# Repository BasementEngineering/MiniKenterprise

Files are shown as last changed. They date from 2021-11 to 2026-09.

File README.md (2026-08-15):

# MOSTY DONE BUT STILL IN PROGRESS

# MiniKenterprise

## What is the Mini Kenterprise ?
The Mini Kenterprise started as a fun little weekend project and turned into a great little drone boat. Its purpose is to get people interested in tech science and ocean exploration. As such it is great for electronics enthusiasts like me but also for students in a workshop setting. 
The Mini Kenterprise, as its name might suggest, is a shrunk down version of a bigger boat. Its "big" sister is a self driving water surveying vessel that was built a couple of years ago and is documented on [Instructables](https://www.instructables.com/Building-a-Self-Driving-Boat-ArduPilot-Rover/).
While the Mini Kenterprise looks similar to it's big sister, it is way easier and also a lot chaeper to build. And it uses off-the-shelf components and fairly common tools.
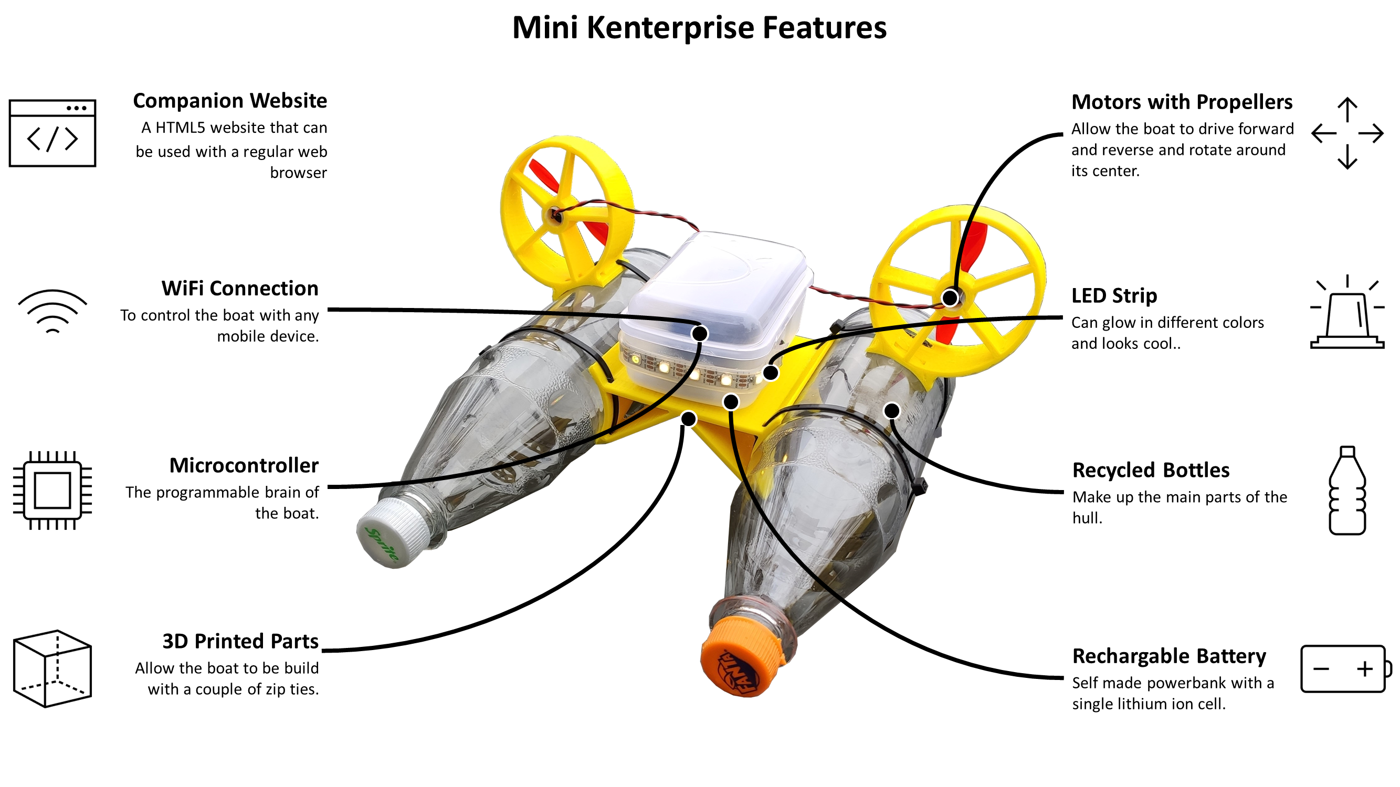
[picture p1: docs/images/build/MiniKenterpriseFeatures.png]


## Why would you want to build one ?
Building a Mini Kenterprise touches on many different engineering disciplines, including 3D printing, soldering, programming and even wireless communication and web technologies.
All packaged in a little RC boat that uses two regular plastic bottles to stay afloat and can be controlled with a smartphone. 
What makes it stand out amongst other RC boats, is that you can build it yourself.
It offers a bunch of features, that can be seen in the graphic above.
It is an air boat, meaning that it moves by using two propellers. It also has a couple of LEDs that can do a cool knight rider effect.
[Here](https://user-images.githubusercontent.com/35432032/155309053-8130b957-cc9e-41b4-a569-48ad077a3d52.mp4) is a video of the first maiden voyage of my first working prototype.

## Check out the new project website
Now most of the information on how to build your own mini kenterprise, including a dynamic bill of materials and a site to program and update it without the need for the Arduino IDE can be found [here](https://basementengineering.github.io/MiniKenterprise/).
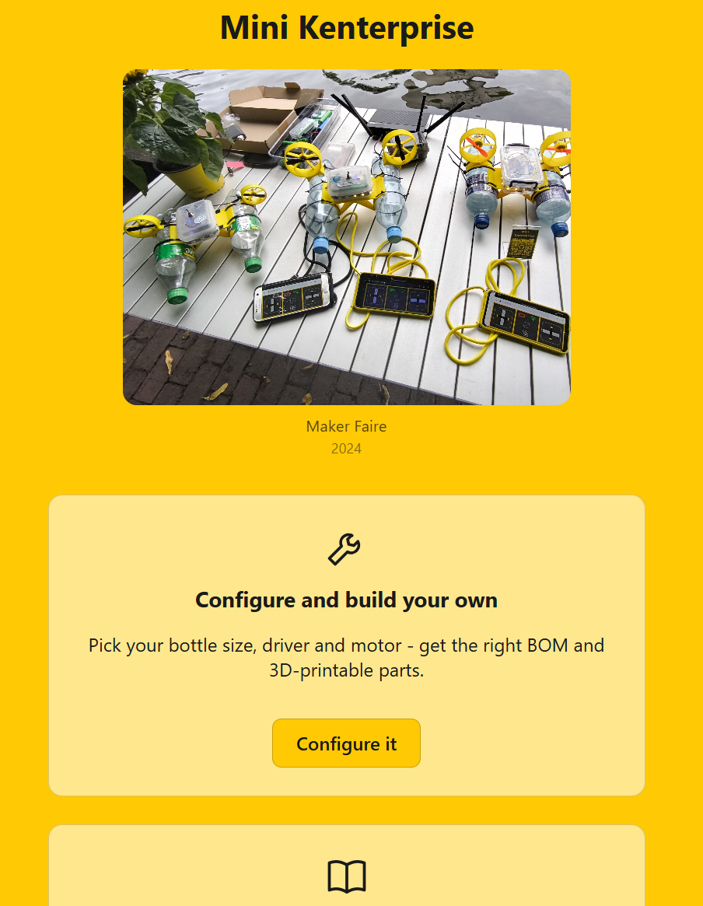
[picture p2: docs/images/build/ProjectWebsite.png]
mini kenterprise project website (https://basementengineering.github.io/MiniKenterprise/)


## Updates
- 2026|07 Programming a Mini Kenterprise no longer requires the Arduino IDE - flash it straight from your browser at the [flashing website](https://basementengineering.github.io/MiniKenterprise/). WiFi credentials and pin assignments are now changed from the boat's own settings page instead of by editing code.
- 2024|09 Working on a new unified hardware architecture for student workshops according to my best practices so far.
- 2024|08 Working on a complete rewrite of the web frontend and a new installation method, that you can already get a taste of in my [duck project](https://www.instructables.com/How-to-Build-an-RC-Duck-With-Arduino-and-Wi-Fi/) with it's nice [duck flashing website](https://basementengineering.github.io/Duck/)

## How Do I Build One ?
Keep in mind that the Mini Kenterprise is not set in stone - it's not an off-the-shelf kit with instructions that tell you 100% exactly how to build it. That said, especially for electronics beginners and student workshops, it's great to have a guide to follow.

The full step-by-step build guide - materials, bottle prep, 3D printing, electronics assembly, soldering, testing, and first launch, all with photos - is on the [project site's Build Guide page](https://basementengineering.github.io/MiniKenterprise/build/) (source: [`docs/build/BuildGuide.md`](docs/build/BuildGuide.md)).

For everything else - the bill of materials, 3D-printable files for your chosen bottle/motor/prop combo, and flashing the firmware straight from your browser - head to the [project site](https://basementengineering.github.io/MiniKenterprise/).

## How does it work? 
The Mini Kenterprise is a "smart" device that can "talk internet". It works as seen in the graphic below. It can host its own WiFi network (access point mode) or connect to an existing WiFi network (station mode). Through this WiFi network it can talk to a variety of other devices, such as the smartphone, that you might have in your pocket, or the laptop, that you might read this on.
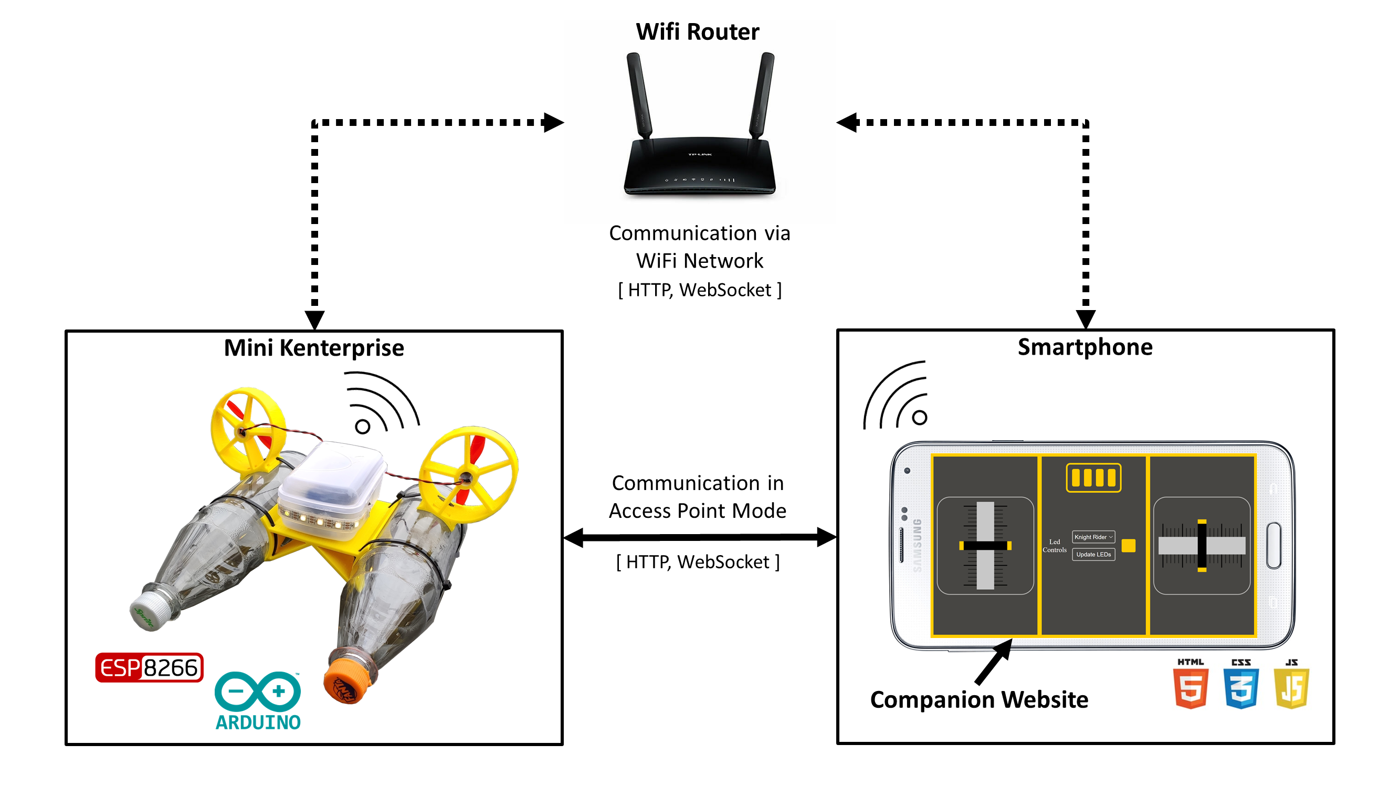
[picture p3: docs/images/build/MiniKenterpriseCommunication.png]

Next to the WiFi connection the boat also has a little webserver, that can serve a companion website. This companion website is a little bit of code, that your phone can access and run, by talking to the server via HTTP. That might sound complicated, but it is simply a matter of opening a websbrowser and entering the boats IP address into the address field.
Once this website is on your phone, it opens a two-way-tunnel to the boats controller. This is called a websocket and it allows the website to send motor control commands to the boat and the boat to send back sensor data.
Thats basically it. The website also has a bunch of nice little buttons and text fields so the data doesn't look that bad. And it features two joysticks that allow you to take control of the boat using your touchscreeen.

## Project History
Before you can start a new DIY Project from Scratch, you will have to do a lot of planning. A lot of designing, building, testing and improving.
Luckyly for you, i already did that and went through a couple of prototypes.
So you will only have to read this if you are interested in the process.
I started with a 3D model, that I designed in Fusion 360. Below you can see a rendering of the latest version.
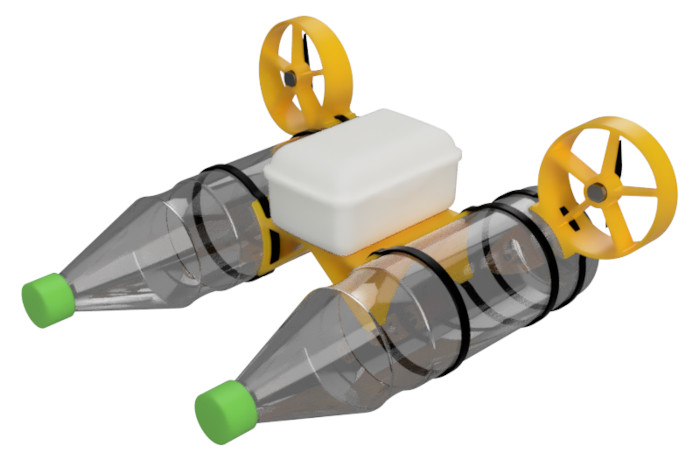
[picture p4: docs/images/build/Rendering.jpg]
Rendering

The circuit diagram was done in PowerPoint. A more professional way would be to draw the circuit diagram in an E-CAD tool such as KiCAD.
However I prefer powerpoint, as it is much easier to understand for Non-Electronics-Experts.

## Hardware Versions So Far
Every variant shares the same type of brain and the same code and user interface. What differs is the size, the motors and the energy source.

This little guide focusses on my "Version 1". This version was built especially for a student workshop, with parts that can be purchased from german suppliers.

Here is a little overview of the other versions in the repository:

- Version 0 aka failure: Was a first test, did not really work out that well.
- Version 1 aka workshop version: Beginner friendly version that was developed with components from german suppliers.
- Version 2 aka small version: Smaller Version that uses 0.5l bottles and small props.
- Version 3 aka fast version: Medium sized version with big fans and 0.75l bottles. Optimized for low weight ans high power.

This guide focusses on version 1 but I have also built other versions that can also be found in this repository.

Here are the major technical differences in a table.
| Version Name 	| Motor | Motor Diameter | Fan Diameter | Bottle Size |
|---|---|---|---|---|
| Version 1	| Arduino 5V Motor Module 	| 12 mm | 75 mm | 1 L	|
| Version 2	| 3.7V Drone Motors 		| 7 mm 	| 45 mm | 0.5 L	|
| Version 2	| 3.7V Motors 			 | 12 mm | 75 mm | 0.75 L|

This repository contains images, circuit diagrams and material list for each version. These files and a dedicated little README can be found under [`docs/images/build/VersionX`](docs/images/build/).

## Key Takeaways So Far
Motors consume a ton of power when starting up and microcontrollers don't like their voltage to dip. In my testing with bigger DC motors, they often didn't even manage to start or starting them took out the entire boat and reset the microcontroller. The reason is the insanely high current draw.
A solution is to either go with a battery that has a high C-rating (discharge rate) and an accompanying battery management system (BMS) that can handle the current. Or to use a low current motor.
In my experiments coreless dc motors proved to consume significantly less power and managed to start up with a small BMS-Board and didn't take the battery out. These motors can be found in cheap tiny drones at the toy store and they are way more fun, than regular dc motors. However, they don't like to be speed regulated, at least my Mini Kenterprise is having trouble going straight with it. Gluing a fin onto the hull, will probably be the easiest fix for that.

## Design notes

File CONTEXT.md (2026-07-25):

# Mini Kenterprise

An ESP8266-based RC boat that people build themselves from a workshop kit, then control from a browser. This context covers the firmware (`MiniKenterpriseCode/`) and its companion web tooling (`minikenterprise_frontend/`, the public site in `docs/`) that get someone from a freshly-soldered board to a boat they can drive, without an Arduino IDE install.

## Language

**Settings**:
The single flat, runtime-editable record of everything a builder might need to change without recompiling: WiFi mode/credentials and the named GPIO pin assignments. Persisted in EEPROM behind a magic-byte validity check; falls back to the compiled-in defaults on first boot or corruption.
_Avoid_: Config (that's the compile-time defaults in `Config.h`, not the runtime record), Preferences (not used here — that's Duck's NVS-based approach).

**Config.h defaults**:
The compiled-in fallback values (pins, AP SSID/password, PWM limits) used only to seed `Settings` the first time the device boots, or after a factory reset. Never read directly at runtime once `Settings` has loaded.
_Avoid_: "the config" as a synonym for `Settings` — they're different lifecycles (one is baked into the firmware image, the other lives in EEPROM and survives reflashing).

**AP mode / Station mode**:
The two WiFi roles the boat can run in, chosen at runtime via `Settings.apMode` (not compile-time anymore). AP mode: the boat hosts its own network and a controller connects to it directly. Station mode: the boat joins an existing WiFi network. If Station mode fails to connect within its timeout, the boat automatically falls back to AP mode so it's never left unreachable.
_Avoid_: "hotspot" for AP mode.

**the site**:
The general public web presence for the project, published from `docs/` (formerly its own `flash-site/` folder — moved so it sits as a sibling of `docs/images/` and `docs/materials/` and can link to them directly, no copying; see `docs/adr/0007-consolidate-site-and-docs-under-docs-folder.md`). Its home page (`index.html`) offers three paths: flashing a prebuilt firmware `.bin` over Web Serial via esp-web-tools (`flash.html`, the "visit a page, click a button" install experience), configuring a new build (`configure.html`, the Variant picker + BOM + STL downloads — see Configurator), and the Build Guide (`docs/build/index.html`, which fetches and renders `docs/build/BuildGuide.md` client-side via the `marked` library loaded from a CDN — no build step, same pattern as esp-web-tools). `docs/materials/BOM.md` remains a maintained, human-readable BOM reference alongside the interactive Configurator, not archival — the material that's actually archival (old workshop slide decks/handouts) lives outside git entirely, in the gitignored top-level `workshop-archive/`.
_Avoid_: "the website" (ambiguous with the on-device control UI served by the firmware itself). "flash-site" (the old folder name — gone; don't reintroduce it in new docs, though you'll still see it in history and older ADRs). "The flashing site" alone, now that it's not flashing-only.

**Variant**:
One specific, buildable combination of the four choices a builder makes — bottle size, motor driver, motor, and its (motor-dependent) prop diameter — that the Configurator resolves to a concrete BOM and a concrete set of STL files to print. Not every combination of the four choices is a Variant; only ones with real, mapped print files in the Configurator's data are offered.
_Avoid_: "Version" (the numbered pin-layout naming this project already retired in `Config.h`'s `// previously "VERSION3"` comment; not being reintroduced for hardware configurations either — note the existing `README.md` "Hardware Versions So Far" section predates this and isn't being renamed as part of this). "Build" (ambiguous with a compiled firmware binary or an `npm run build`).

**Configurator**:
`docs/configure.html` and its `docs/js/` modules — lets a prospective builder pick a Variant and see the resulting BOM and STL download links, before anything is built or flashed. Distinct from the Control UI (runs on an already-built, already-flashed boat) and from flashing (installs firmware onto already-built hardware).

**Control UI**:
The on-device web app (built from `minikenterprise_frontend/`, embedded into the firmware binary as PROGMEM byte arrays) that a builder's browser loads directly from the boat over WiFi, to drive it and adjust `Settings`.
_Avoid_: "frontend" alone — ambiguous between this and the site.

**Dev stub**:
A dev-only Node script (`minikenterprise_frontend/dev-stub.js`) that mocks both wire protocols the Control UI speaks to the real firmware — the `/api/settings` GET/POST HTTP protocol and the boat-control WebSocket on `:81` — so the whole Control UI, settings page and live boat control alike, can be developed, driven, and debugged locally without a flashed board. It logs every decoded control command to the terminal and replies to heartbeats/pushes simulated status so the UI behaves as if connected.
_Avoid_: confusing with `FrontendServer` or the firmware's `WebSocketsServer` (the real on-device servers) — the stub only exists on a developer's machine, never in firmware, and mirrors protocol shape only, not EEPROM storage, restart semantics, or real motor/LED behavior.

## Example dialogue

> "Where does someone change the boat's WiFi password?"
> "The Control UI's settings page — it reads and writes `Settings`, not `Config.h`. `Config.h` only matters on first boot, to seed the default `Settings`."
>
> "And if they type the wrong WiFi password for Station mode?"
> "It tries to connect, times out, and falls back to AP mode automatically — they reconnect to the boat's own network and fix it from there."
>
> "Is that the same page as the site?"
> "No — the site (`docs/`) is a separate, public site. Its flashing page installs the `.bin` the first time. The Control UI only exists once the firmware is already on the board."
>
> "Where do I find out what parts I need to build one?"
> "The site's Configurator — pick a Variant (bottle size, driver, motor, prop) and it resolves the BOM and STL downloads for that exact combination. `docs/materials/BOM.md` is still a maintained reference too, just not interactive."

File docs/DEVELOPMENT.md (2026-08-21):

# Development Quickstart

This repo has three independently runnable pieces: the Control UI **frontend** (`minikenterprise_frontend/`), the **firmware** (`MiniKenterpriseCode/`), and the public **site** (`docs/`). Each section below covers one.

## Frontend

```
cd minikenterprise_frontend
npm install        # once
npm run dev-stub   # terminal A - mocks the boat's settings HTTP API (:8787) and control WebSocket (:81)
npm run dev        # terminal B - Vite dev server
```

Open:
- Control UI: http://localhost:5173/
- Settings page: http://localhost:5173/settings/

No hardware needed — `dev-stub` fakes both wire protocols the firmware speaks (settings + boat control), replies to heartbeats, and drifts simulated battery/network status. Watch the `dev-stub` terminal to see every command the frontend sends, decoded live (e.g. `[control] recv: ControlLR 45 -10`). See `docs/adr/0005-unify-dev-stub-for-boat-control-and-settings.md`.

## Building the frontend and embedding it into the firmware

The firmware serves the frontend from flash as PROGMEM byte arrays, not from a filesystem (`docs/adr/0001-embed-frontend-as-progmem.md`), so it has to be re-encoded after every frontend change.

Full pipeline, one command from the repo root (builds, encodes, and copies the generated headers into `MiniKenterpriseCode/`):
```
.\deployFrontend.ps1
```

Or step by step:
```
cd minikenterprise_frontend
npm run build                              # -> dist/
python ../tools/encodeInArduino.py dist     # -> dist/website_content.h + website_functions.h
```

**Size**: `encodeInArduino.py` prints a per-file size and a total, e.g.:
```
Total embedded size: 76829 bytes across 8 files
```
That's flash usage (PROGMEM), not RAM — it doesn't compete with the ESP8266's heap. The number that actually matters is the "Sketch uses X bytes (Y%) of program storage space" line the Arduino IDE/`arduino-cli` prints after compiling `MiniKenterpriseCode.ino`, which is bounded by the flash-size partition chosen for the board (Tools > Flash Size in the IDE). Check that after any frontend growth, not just the embed-step total — there's no automated budget check for either number yet.

## Testing options

No automated test suite exists yet — the project relies on manual testing instead:
- **Frontend only**: `npm run dev-stub` + `npm run dev` (above), drive the Control UI/settings page in a browser, and watch the stub terminal for exactly what gets sent. This isolates frontend bugs from backend/hardware bugs before ever touching a board.
- **Full firmware, on real hardware**: flash a board (below) and exercise the actual control loop, motor output, EEPROM-backed settings persistence, and AP/Station WiFi fallback — none of which the stub simulates.

## Firmware: developing and uploading

Source lives in `MiniKenterpriseCode/`, with `MiniKenterpriseCode.ino` as the sketch entry point.

- **Arduino IDE** (1.x or 2.x): open `MiniKenterpriseCode.ino`, select your board (Wemos D1 Mini: "LOLIN(WEMOS) D1 R2 & mini"), then Sketch > Upload.
- **arduino-cli**:
  ```
  arduino-cli compile --fqbn esp8266:esp8266:d1_mini MiniKenterpriseCode
  arduino-cli upload --fqbn esp8266:esp8266:d1_mini -p <PORT> MiniKenterpriseCode
  ```

Re-run the frontend build/embed step above first if you changed anything under `minikenterprise_frontend/` — the checked-in `website_content.h`/`website_functions.h` don't regenerate themselves.

## The site (`docs/`): running it locally and releasing

`docs/` is a plain static site (no build step) published via GitHub Pages (`.github/workflows/pages.yml` uploads `docs/` as-is — no CI build step either). It lives under `docs/` specifically so it can reference `docs/images/` and `docs/materials/` with plain relative links, instead of copying them into a separate folder. It has three paths from its home page: flashing a prebuilt `.bin` straight from the browser via Web Serial (`flash.html`), configuring a new build — picking a bottle/driver/motor/prop Variant to get the right BOM and STL downloads (`configure.html`) — and the Build Guide (`docs/build/index.html`), which fetches `docs/build/BuildGuide.md` and renders it client-side with the `marked` library loaded from a CDN (same no-build-step approach as `flash.html`'s esp-web-tools). Since `docs/build/index.html` sits in the same folder as `BuildGuide.md`, the guide's relative image/file links (e.g. `../images/build/...`, `../../3dFiles`) resolve correctly without any rewriting — edit `BuildGuide.md` like any other markdown file and the rendered page picks it up as-is.

`BuildGuide.md` always covers the current recommended Variant only (Vorarlberg as of this writing) — older guides for superseded setups aren't deleted, just renamed to `BuildGuide_<Name>.md` and added to the `GUIDES` map in `docs/build/index.html`'s script, which switches between them via a `?guide=<name>` query param (the same query-string-as-state idiom `configure.html`'s `js/urlState.js` uses for Variant picks). Add a small link for each archived guide to the `.guide-switcher` nav in `docs/build/index.html` so it stays reachable.

To preview any of them locally:
```
cd docs
python -m http.server 8080
```
Open http://localhost:8080 — Web Serial requires a secure context, and `localhost` counts as one, so this works without HTTPS. Actually flashing still needs a real board plugged in over USB, in Chrome or Edge. `configure.html` needs no hardware; its STL download links point at `raw.githubusercontent.com/BasementEngineering/MiniKenterprise/main/3dFiles/...`, so they fetch from the pushed `main` branch even when previewing locally — a new STL you haven't pushed yet won't download until it's on `main`. The Build Guide needs internet access (to load `marked` from the CDN) even when previewing locally.

The home-page gallery registers `docs/sw.js` as a service worker. After one successful online visit, it caches the home page shell, gallery manifest, and every current gallery image so the carousel can run offline. Cache paths are derived from the service worker scope, so this works on the GitHub Pages project URL and at the local preview URL.

### Releasing a new firmware build

1. Build the frontend and regenerate the embedded-website headers: `.\deployFrontend.ps1` (repo root).
2. Compile `MiniKenterpriseCode.ino` (Arduino IDE or `arduino-cli`) and export the binary as `esp8266.bin`.
3. Copy it to `docs/firmware/esp8266.bin`, overwriting the previous one.
4. Bump `"version"` in `docs/firmware/manifest.json`.
5. Commit and push — the Pages workflow republishes `docs/` automatically.

### Releasing a configurator/BOM update

1. Update `docs/materials/motorsAndProps.csv` and/or hand-edit `docs/js/data/variants.js` to reflect new motors/props/BOM parts/STL mappings. If you add a new fan-enclosure STL, drop it into the right `3dFiles/<bottle>_Bottle/` folder — name it `FanEnclosure_<bottle>_M<motorDiameter>_P<propDiameter>.stl` to be picked up automatically, or add an entry to `variants.js`'s `legacyOverrides` if it doesn't follow that convention. Component/gallery photos live under `docs/images/components/` and `docs/images/gallery/` respectively and are referenced directly — no copy step.
2. Run `.\deployConfiguratorAssets.ps1` (repo root) — this rescans `3dFiles/` and regenerates `docs/js/data/stl-manifest.json`.
3. Preview locally (above) — click through `configure.html`, checking that picker enabling/disabling looks right. STL download links will only resolve against files already on `main`.
4. Commit `docs/js/data/variants.js` and `stl-manifest.json` (and any new files under `3dFiles/`), and push — the Pages workflow republishes `docs/` automatically.

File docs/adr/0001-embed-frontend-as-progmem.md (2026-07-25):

# Embed the Control UI as PROGMEM byte arrays instead of a filesystem

The Control UI used to be served from SPIFFS, which required a separate "ESP8266 Sketch Data Upload" step only supported by Arduino IDE 1.x — the main friction point in getting a Mini Kenterprise running. We're instead building the frontend with Vite and baking the output directly into the firmware as `PROGMEM` byte arrays (ported from the Duck project's `encodeInArduino.py`), so flashing the firmware is the only step. The trade-off is a larger firmware binary and an extra build step before compiling, but it removes the filesystem entirely and works with any Arduino toolchain (including IDE 2.x and `arduino-cli`).

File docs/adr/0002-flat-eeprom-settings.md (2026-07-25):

# Flat EEPROM struct for runtime settings, not Preferences/LittleFS/JSON

Duck (a sibling project sharing this firmware base) built a `Preferences`-backed, JSON-schema-driven settings system supporting pluggable per-motor driver types — flexible, but the kind of "support every hardware variant" complexity that previously made this codebase hard to maintain. Mini Kenterprise's settings are deliberately scoped down to what builders actually asked for: WiFi credentials and named pin numbers, nothing pluggable. We're storing this as one fixed-size struct via the ESP8266 core's EEPROM-emulation library, validated with a magic byte, with no JSON library or filesystem involved. If a genuine need for per-hardware-variant driver configuration reappears, that's a separate future decision, not something to bolt onto this struct.

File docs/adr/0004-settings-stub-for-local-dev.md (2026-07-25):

# Local Settings stub for offline dev/testing

The Settings page's `/api/settings` GET/POST calls have no backend when running `npm run dev`, blocking local iteration on layout and save/load behavior before flashing hardware. We considered proxying to a real device on the LAN (requires hardware always on hand) and a client-side fetch mock inside `settings.js` (duplicates protocol parsing into production code). Instead we added a small standalone dev-only Node script (`minikenterprise_frontend/settings-stub.js`) that fakes the same `key=value` wire protocol from an in-memory object, proxied via Vite. It mirrors the protocol shape only, not EEPROM storage or restart semantics, so it's a test double alongside the real `Settings` (ADR 0002), not a second implementation of it.

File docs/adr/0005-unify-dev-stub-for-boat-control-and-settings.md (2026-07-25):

# Extend the Settings stub into a unified dev stub covering boat control too

`docs/adr/0004-settings-stub-for-local-dev.md` gave the Settings page a local backend, but the Control UI's boat-control channel (a WebSocket on `:81`, see `MiniKenterpriseCode/Parser.h`) had no equivalent — with nothing listening on `:81` during `npm run dev`, the socket fails silently and the UI just sits in its offline/error state, indistinguishable from a real firmware bug. That ambiguity made it hard to separate frontend bugs from backend/hardware bugs while developing without a flashed board.

We replaced `settings-stub.js` with `minikenterprise_frontend/dev-stub.js`, a single dev-only Node process that mocks both wire protocols the Control UI speaks: the existing `/api/settings` HTTP mock, unchanged, plus a new WebSocket mock on `:81` (using the `ws` package) that decodes and logs every incoming control command to the terminal, replies to `Heartbeat` so the UI's online/offline state behaves correctly, and pushes slowly drifting `Status` messages so battery/network indicators visibly react. The control mock reuses `Parser`/`Communication_Commands` from `src/my_modules/parser.js` directly rather than reimplementing the wire format, so the mock can't drift out of sync with the real frontend protocol logic.

This gives one command (`npm run dev-stub`) and one terminal to fully develop and debug the Control UI — both pages, both channels — without hardware, and to watch exactly what the frontend sends before deciding whether a bug is a frontend, backend/firmware, or hardware issue. As before, it mirrors protocol shape only (no EEPROM persistence, no real motor/LED behavior, no restart semantics) — a test double, not a second implementation.

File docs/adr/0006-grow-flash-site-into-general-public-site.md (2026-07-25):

# Grow flash-site into the general public site, not a separate configurator project

Builders now need to pick a bottle size, driver, motor and prop before they can get a correct BOM and STL set — a real feature (the Configurator), not a documentation tweak. We're adding it as `configure.html` inside the existing `flash-site/` directory, alongside a new `flash.html` and a chooser `index.html`, rather than starting a second static site or repo. `flash-site/` was already a GitHub Pages target with its own publish workflow, its own "no build step" convention, and its own stylesheet — reusing all three means one Pages workflow, one link from the root `README.md`, and one place a builder lands regardless of which of the two things (flash vs. configure) they came for. The cost is that `flash-site` becomes a mild misnomer — it's no longer just the flashing page — and its `flash-site/**`-triggered deploy now couples releases of two previously-unrelated concerns (firmware distribution and parts/print selection). We're accepting that cost rather than renaming the folder or splitting the deploy pipeline; the folder keeps its name.

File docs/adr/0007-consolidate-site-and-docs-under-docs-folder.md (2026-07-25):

# Move the public site into docs/, stop copying assets into it, drop the workshop archive from git

`flash-site/` needed everything GitHub Pages would serve to physically live inside it, since Pages publishes one directory as-is with no build step. That meant `deployConfiguratorAssets.ps1` copied BOM component photos, variant hero photos, and a subset of `3dFiles/` STLs into `flash-site/img/` and `flash-site/downloads/`, and every copy got committed to git alongside its source — doubling real binary content for no benefit. We're moving the site itself into `docs/` (its HTML/CSS/JS/firmware, previously `flash-site/*`) so it becomes a sibling of `docs/images/` and `docs/materials/` instead of a separate folder needing copies of them: the Configurator now links to `docs/images/components/...` and `docs/images/gallery/...` directly, and STL "download" links point straight at `raw.githubusercontent.com/BasementEngineering/MiniKenterprise/main/3dFiles/...` (an accepted pattern for occasional, user-initiated downloads, as opposed to images loaded on every page view, which stay served by Pages' own CDN). `deployConfiguratorAssets.ps1` now only rescans `3dFiles/` and regenerates the tiny `stl-manifest.json`; the Pages workflow (`path: docs`) needs no build step of its own. The site's public URL is unchanged, since `docs/index.html` still serves at the Pages root.

Existing images were reorganized into `docs/images/{components,gallery,build}/` — `components/` for BOM part photos (was `docs/materials/images/`), `gallery/` for "finished boat" inspiration photos (was root `images/*_Variant_*`, meant to grow substantially once a scrolling gallery ships on the site), and `build/` for everything else that used to live in the repo-root `images/` folder (hardware-version galleries, soldering tips, diagrams), moved wholesale. The repo-root `README.md`'s old step-by-step build walkthrough moved into `docs/build/BuildGuide.md` alongside those photos, leaving `README.md` a short entry point that links out to the guide and the site for BOM/3D files/flashing — the intent being that `docs/` grows into a one-stop shop (BOM with purchasing links, build steps, pinout for the recommended version, flashing) while the root README stays a lean front door.

Also folded in here: the old workshop presentation archive (`docs/workshop/`, several hundred MB of pptx/docx/pdf, never actually committed) moved to a gitignored top-level `workshop-archive/` — kept on disk, never pushed to GitHub, and no longer nested under whatever `docs/` publishes.

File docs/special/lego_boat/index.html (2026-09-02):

← Back to Mini Kenterprise

Mini Kenterprise Special Edition

# LEGO Mini Kenterprise

LEGO Mini Kenterprise pairs the standard Mini Kenterprise electronics with two 3D-printed paddle wheels, driven by waterproof N20 gear motors, bolted onto a LEGO boat hull. This is a fixed reference build, made for builders who want to reproduce this particular project rather than configure a boat.

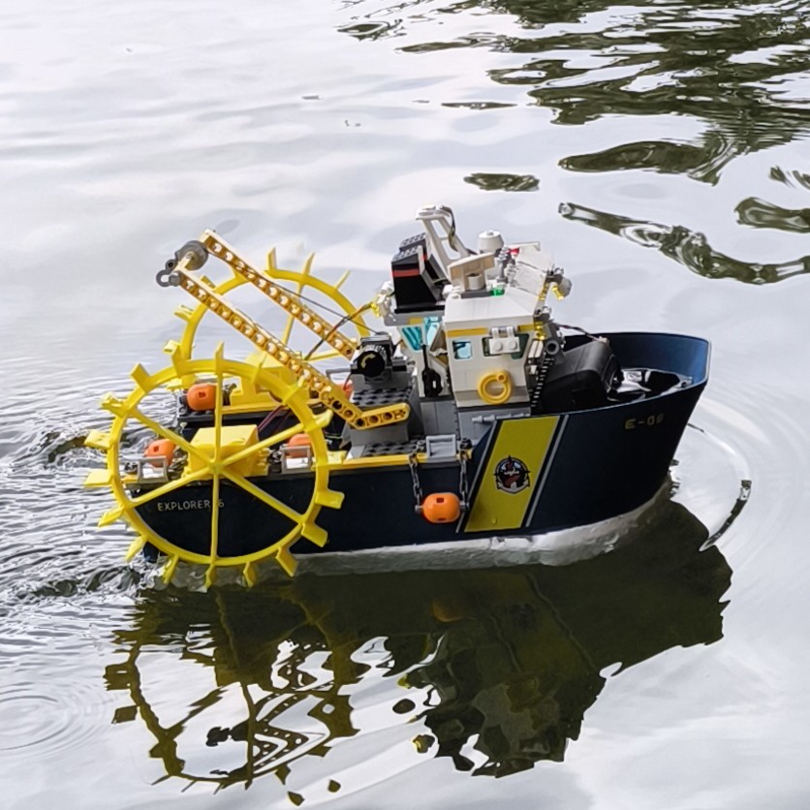
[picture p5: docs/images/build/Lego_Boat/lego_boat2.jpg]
LEGO Mini Kenterprise afloat, showing the LEGO hull and one of its paddle wheels


## Reference bill of materials

This list documents the reference build only. It intentionally has no purchasing links, as I won't be able to keep them up to date. Refer to the original Kenterprise components for sourcing. You will have to search for the special parts yourself in your online store of choice.

Part | Qty. | Reference notes
LEGO boat hull | 1 | Provides the hull and superstructure. Any similarly-sized LEGO ship set works - ours was an exploration/tug-style set.
Waterproof N20 gear motor | 2 | One motor drives each paddle wheel. Sourced as "DC 3V 6V Waterproof N20 DC Gear Motor 48RPM-96RPM Slow Speed".
5V USB power bank | 1 | Powers the whole boat directly - no separate battery, charger, or booster circuit needed.
Wemos D1 Mini | 1 | Microcontroller for the control platform, same as the standard build.
DRV8833 dual H-bridge driver | 1 | Drives the two motors.
Prototype board and pin headers | 1 | For the controller and power wiring.
Toggle switch | 1 | Main power switch.
Hookup wire, heat-shrink tubing, M3 hardware, and standoffs | As needed | Choose lengths to suit the printed motor mounts and your wiring.

## 3D-printable parts

Print two of each - one motor mount and one paddle wheel per side. Download links point directly to the project repository.

- Download MotorMount.stl (https://raw.githubusercontent.com/BasementEngineering/MiniKenterprise/main/3dFiles/special/lego_boat/MotorMount.stl)
- Download Waterwheel.stl (https://raw.githubusercontent.com/BasementEngineering/MiniKenterprise/main/3dFiles/special/lego_boat/Waterwheel.stl)

## Reference build

LEGO Mini Kenterprise afloat, three-quarter view

Completed boat, underway.

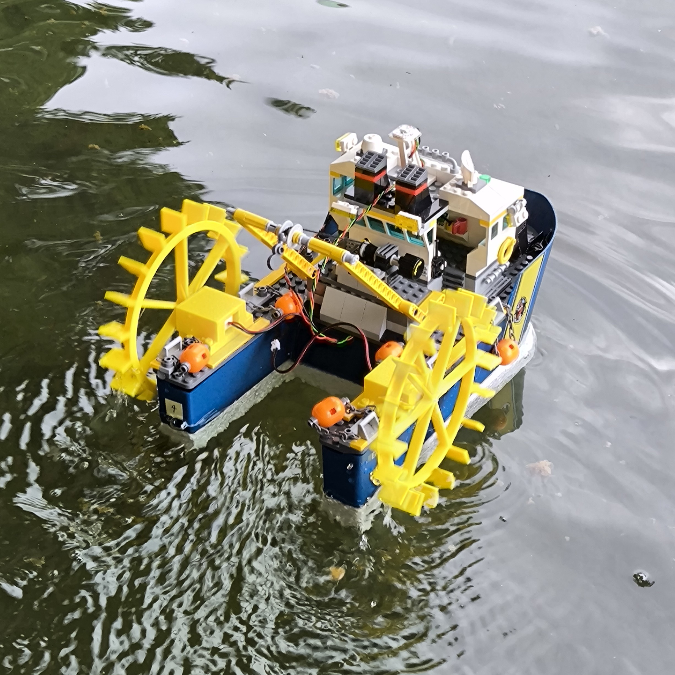
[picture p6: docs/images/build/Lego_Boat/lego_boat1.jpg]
Close-up of the two 3D-printed paddle wheels and motor mounts


Paddle wheels and motor mounts, one per side.

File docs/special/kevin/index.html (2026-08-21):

← Back to Mini Kenterprise

Mini Kenterprise Special Edition

# Kevin

Kevin is a two-wheel robotic car built around the Mini Kenterprise control platform. This is a fixed reference build, made for builders who want to reproduce this particular project rather than configure a boat.

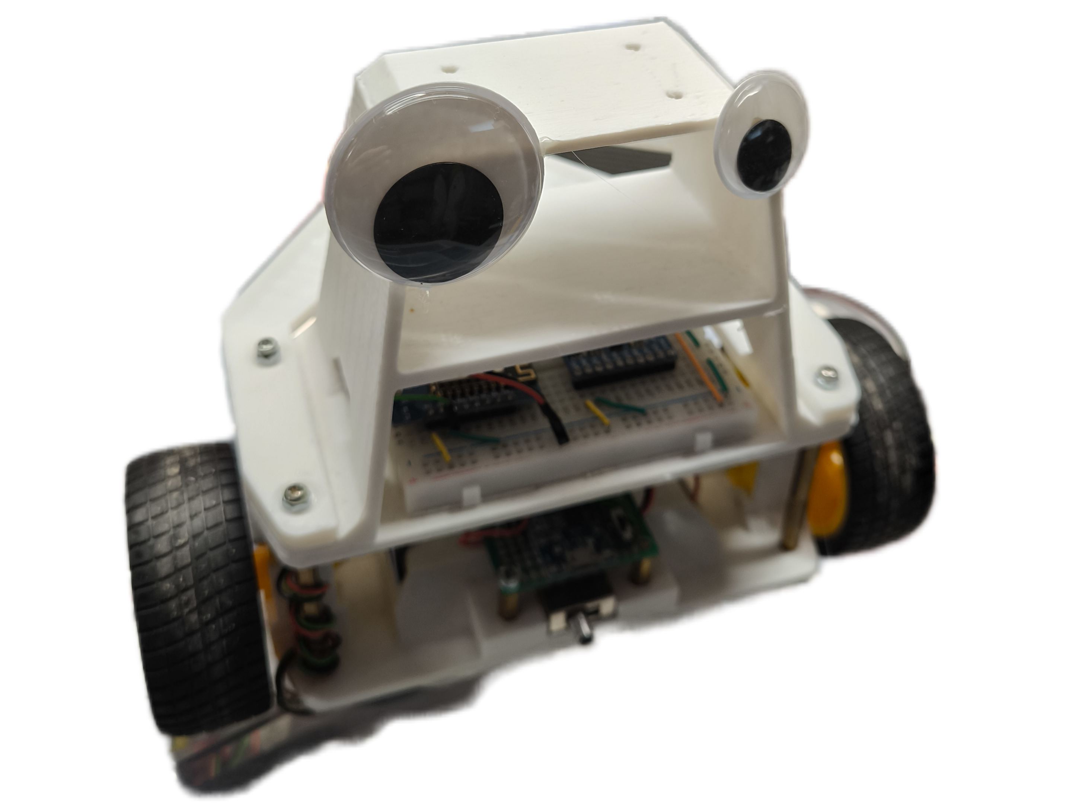
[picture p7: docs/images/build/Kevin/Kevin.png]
Kevin, the assembled two-wheel robotic car


## Reference bill of materials

This list documents the reference build only. It intentionally has no purchasing links, as I won't be able to keep them up to date. Refer to the original Kenterprise components for sourcing. You will have to search for the special parts yourself in your online store of choice.

Part | Qty. | Reference notes
TT gear motor | 2 | One motor drives each wheel.
Compatible wheel | 2 | Used with the TT gear motors.
Wemos D1 Mini | 1 | Microcontroller for the control platform.
DRV8833 dual H-bridge driver | 1 | Drives the two motors.
18650 Li-Ion cell | 1 | Power source for the reference build.
TP4056 charging module | 1 | Used for charging the 18650 cell, charger only.
1S 15A Li-Ion BMS board | 1 | Used to protect the battery.
Prototype board and pin headers | 1 | For the controller and power wiring.
Toggle switch | 1 | Main power switch.
Hookup wire, heat-shrink tubing, M3 hardware, and standoffs | As needed | Choose lengths to suit the printed chassis and your wiring.

## 3D-printable parts

The chassis is made from the four files below. Download links point directly to the project repository.

- Download Baseplate.stl (https://raw.githubusercontent.com/BasementEngineering/MiniKenterprise/main/3dFiles/special/kevin/Baseplate.stl)
- Download MiddlePlate.stl (https://raw.githubusercontent.com/BasementEngineering/MiniKenterprise/main/3dFiles/special/kevin/MiddlePlate.stl)
- Download RearWheel_Holder.stl (https://raw.githubusercontent.com/BasementEngineering/MiniKenterprise/main/3dFiles/special/kevin/RearWheel_Holder.stl)
- Download top.stl (https://raw.githubusercontent.com/BasementEngineering/MiniKenterprise/main/3dFiles/special/kevin/top.stl)

## Reference build

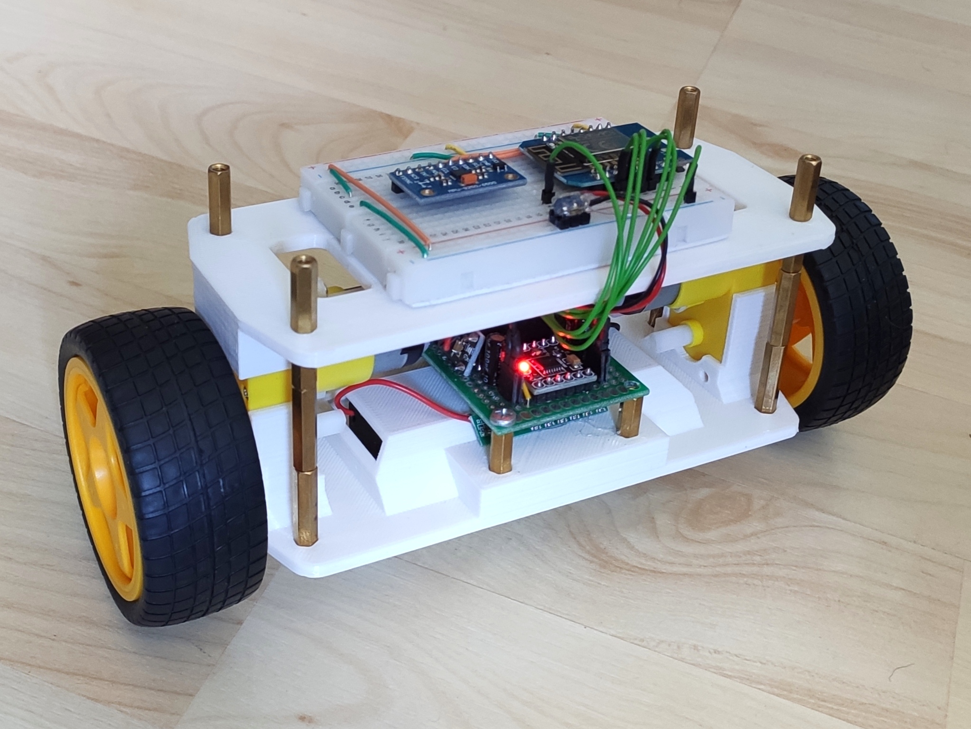
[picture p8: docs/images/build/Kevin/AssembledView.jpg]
Assembled Kevin robotic car


Completed chassis.

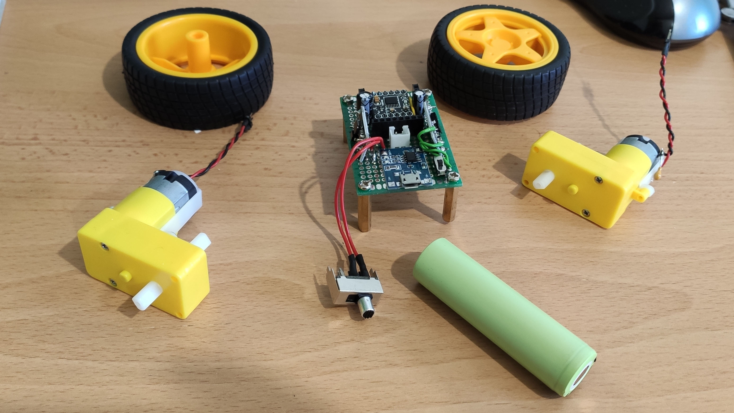
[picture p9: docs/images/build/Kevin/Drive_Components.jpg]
Kevin's wheels, gear motors, controller board, and battery


Drive, battery, and control components.

Top view of Kevin's battery compartment

Battery compartment from above.

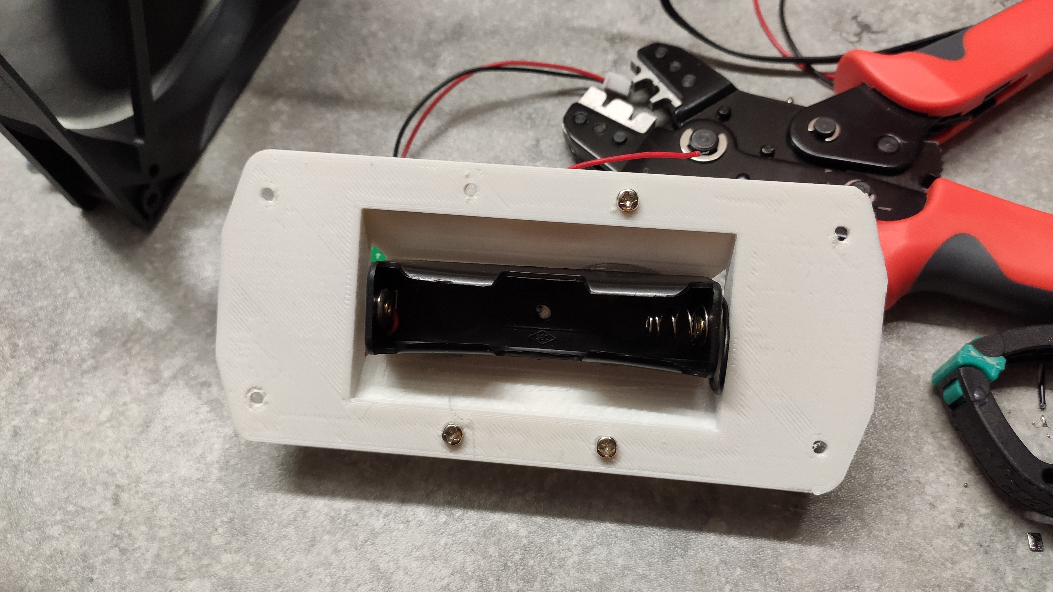
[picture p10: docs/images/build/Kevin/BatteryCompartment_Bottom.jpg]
Bottom view of Kevin's battery compartment


Battery compartment from below.

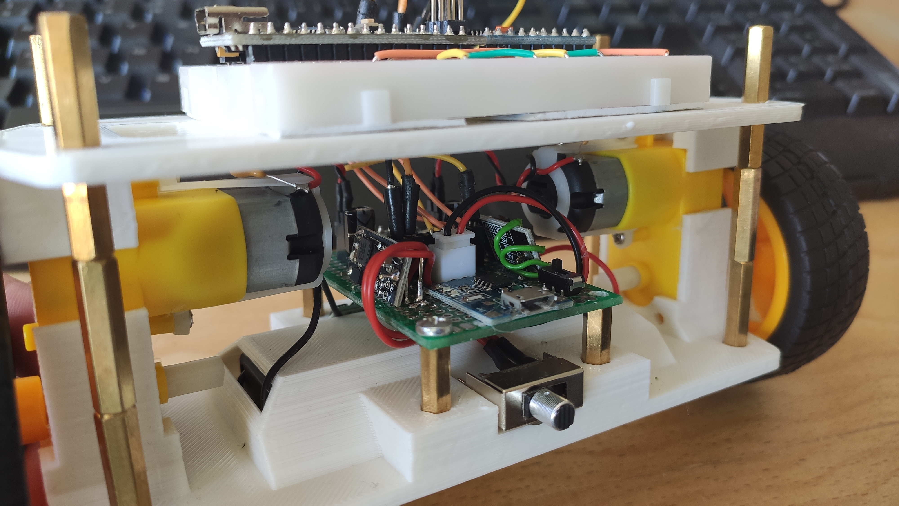
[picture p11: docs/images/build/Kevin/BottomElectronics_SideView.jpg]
Side view of Kevin's lower electronics


Lower electronics and motor wiring.

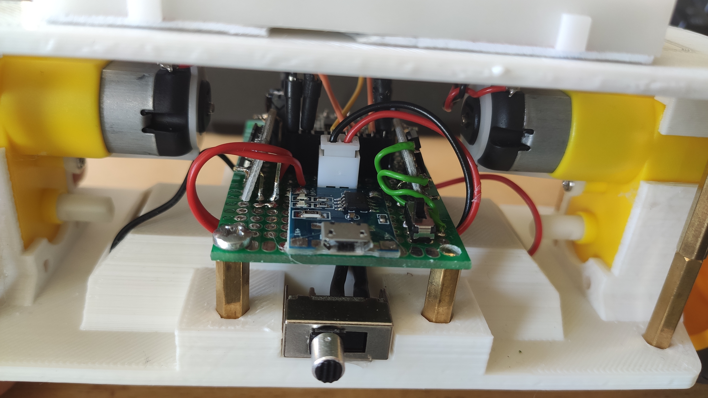
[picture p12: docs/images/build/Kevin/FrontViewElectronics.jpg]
Front view of Kevin's electronics


Front electronics view.

Kevin PCB layout reference image

PCB layout reference.

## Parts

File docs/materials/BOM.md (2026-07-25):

# Bill Of Materials (2024 Workshop in Austria)
This is the bill of materials for a workshop situation. With enough materials to build (at least) 10 mini Kenterprises.

## ToDo
I really need a csv to md bom converter.

I need to add images for the components.

List items:
- Position
- Component
- Image
- Description
- Link
- Quantity (per boat)
- Quantity (in package)
- Quantity (nr of packages)
- Pice (Whole)
- Price (Per Boat)

## Electronics

### 1 Microcontroller
| Position | Component | Description | Quantity | Link |
|---|---|---|---|---|
| 1 | Microcontroller | Wemos D1 Mini | 1x | [Aliexpress](https://de.aliexpress.com/item/32831353752.html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), [AZ-Delivery](https://www.az-delivery.de/products/d1-mini) |

### 2 Motors and Drivers
| Position | Component | Description | Quantity | Link |
|---|---|---|---|---|
| 2.1 | Motor + Prop | DRV8833 Dual H-Bridge | 2x |  [amazon]() |
| 2.2 | Motor Driver | DRV8833 Dual H-Bridge | 1x |  [amazon]() |

### 3 Power Supply
| Position | Component | Description | Included Quantity | Required per Boat | Order Amount | Link | Price |
|---|---|---|---|---|---|
| 3.1 | Battery | 18650 Li-Ion Cell | 1x | | [amazon]() |
| 3.2 | Charger and BMS | TP4056 with protection | 10 | 1 | 1 | [amazon](https://www.reichelt.de/entwicklerboards-ladeplatine-fuer-3-7v-li-akkus-micro-usb-1a-debo2-3-7li-1-0a-p291400.html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)
| 3.3 | Battery Holder | 18650 Holder | 10 | 1 |[reichelt](https://www.reichelt.de/batteriehalter-fuer-1-18650-zelle-pin-halter-ha-1x18650-p141630.html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) |
| 3.4 | Switch | 2 Pin Toggle Switch | 10 | 1 | |
| 3.5 | Voltage Booster | 5V 1A Boost | 10 | 1 | [Amazon](https://www.amazon.de/DollaTek-multifunktionales-DC-Lithium-Batterie-Boost-Modul-Step-Up-Board-Wandler-Spannungsregler/dp/B08HQQ32M2) |

## 4 Connection Equiptment
| Position | Component | Description | Quantity | Link |
|---|---|---|---|---|
| 4.1 | Breadboard | 400 dots | 1x | [AZ-Delivery](https://www.az-delivery.de/products/mini-breadboard?_pos=1&_sid=12607a080&_ss=r) |
| 4.2 | Jumper Wires | stiff | 1x | [reichelt](https://www.reichelt.de/steckbruecken-drahtbruecken-set-140-teilig-steckboard-dbs-p79056.html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) |
| 4.3 | Pins |Male Pin Headers | 20x | [Kein Link]() |
| 4.4 | RGB LED | Neopixel WS2812b strip (60LEDs/m) | 6 LEDs | [reichelt](https://www.reichelt.de/entwicklerboards-flora-rgb-smart-neopixel-4er-pack-ws2811-debo-np-f-rgb-p235471.html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) |
| 4.5 | Resistor | 180 kOhm | 1x | [reichelt](https://www.reichelt.de/widerstand-metalloxyd-180-kohm-0207-1-0-w-5--1w-180k-p1791.html?&trstct=pos_3&nbc=1)|

## 5 LEDs
| Position | Component | Description | Quantity | Link |
|---|---|---|---|---|
| 5 | RGB LED | Neopixel WS2812b strip (60LEDs/m) | 6 LEDs | [reichelt](https://www.reichelt.de/entwicklerboards-flora-rgb-smart-neopixel-4er-pack-ws2811-debo-np-f-rgb-p235471.html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) |

## Hardware

### Bottles
| Position | Component | Description | Quantity | Link |
|---|---|---|---|---|
| 1 | Bottle | hard plastic 0.5l (eg. Coke, Sprite, ...) | 2x | |

### 3D Printed Parts
| Position | Component | Description | Quantity | Link |
|---|---|---|---|---|
| 2 | Centerpiece | 3D printed electronics enclosure | 1x | |
| 3 | Fan Holder | 3D printed | 2x | |

### Further Components
| Position | Component | Description | Quantity | Link |
|---|---|---|---|---|
| 4 | Mini Lunch Box | Plastic Container | 1x | |
| 5 | Ziptie | 200mm long, 4.3mm wide | 6x | |

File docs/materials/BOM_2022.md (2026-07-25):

# Bill Of Materials (2022 Workshop in Wilhelmshafen, Germany)
Here are the parts that you need for version 1.

Electronics to buy:
| Position | Component | Description | Quantity | Link |
|---|---|---|---|---|
| 1 | Breadboard | 400 dots | 1x | [AZ-Delivery](https://www.az-delivery.de/products/mini-breadboard?_pos=1&_sid=12607a080&_ss=r) |
| 2 | Jumper Wires | stiff | 1x | [reichelt](https://www.reichelt.de/steckbruecken-drahtbruecken-set-140-teilig-steckboard-dbs-p79056.html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) |
| 3 | Pins |Male Pin Headers | 20x | [Kein Link]() |
| 4 | Battery | 18650 Li-Ion Cell | 1x | [reichelt](https://www.reichelt.de/industriezelle-18650-3-6-v-2850-mah-ungeschuetzt-1er-pack-sam-18650-29e-s-p278089.html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) |
| 5 | Battery Holder | 18650 Holder | 1x | [reichelt](https://www.reichelt.de/batteriehalter-fuer-1-18650-zelle-pin-halter-ha-1x18650-p141630.html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) |
| 6 | Charger | TP4056 without protection | 1x | [reichelt](https://www.reichelt.de/entwicklerboards-ladeplatine-fuer-3-7v-li-akkus-micro-usb-1a-debo2-3-7li-1-0a-p291400.html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)
| 7 | BMS | min. 3A Output | 1x | [Aliexpress](https://de.aliexpress.com/item/4001010955646.html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)
| 8 | Switch | 2 Pin Toggle Switch | 1x | |
| 9 | Voltage Booster | 5V 3A Boost | 1x | [AZ-Delivery](https://www.az-delivery.de/products/mt3608-dc-dc-step-up-modul-1) |
| 10 | Motor + Driver + Prop | DRV8833 Dual H-Bridge | 1x |  [reichelt](https://www.reichelt.de/entwicklerboards-luefter-mit-propeller-modul-l9110-debo-fan-l9110-p282643.html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) |
| 11 | Microcontroller | Wemos D1 Mini | 1x | [Aliexpress](https://de.aliexpress.com/item/32831353752.html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), [AZ-Delivery](https://www.az-delivery.de/products/d1-mini) |
| 12 | RGB LED | Neopixel WS2812b strip (60LEDs/m) | 6 LEDs | [reichelt](https://www.reichelt.de/entwicklerboards-flora-rgb-smart-neopixel-4er-pack-ws2811-debo-np-f-rgb-p235471.html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) |
| 13 | Resistor | 180 kOhm | 1x | [reichelt](https://www.reichelt.de/widerstand-metalloxyd-180-kohm-0207-1-0-w-5--1w-180k-p1791.html?&trstct=pos_3&nbc=1)|

Further Components..
| Position | Component | Description | Quantity | Link |
|---|---|---|---|---|
| 1 | Bottle | hard plastic 1l (eg. Coke, Sprite, ...) | 2x | |
| 2 | Centerpiece | 3D printed electronics enclosure | 1x | |
| 3 | Fan Holder | 3D printed | 2x | |
| 4 | Mini Lunch Box | Plastic Container | 1x | |
| 5 | Ziptie | 200mm long, 4.3mm wide | 6x | |

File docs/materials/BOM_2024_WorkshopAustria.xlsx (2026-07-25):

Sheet: Input
Number of Boats | 15
Component Price | 507.72
Price per Boat | 33.848
Number of Boats | 9 | 1 | 2 | 3 | 4 | 5 | 6 | 7 | 8 | 9 | 10 | 11 | 12 | 13 | 14 | 15 | 16 | 17 | 18 | 19 | 20
Prive per Boat | 33.85 | 226.60 | 113.30 | 75.53 | 56.65 | 49.32 | 53.28 | 45.67 | 40.96 | 39.46 | 35.52 | 44.34 | 40.64 | 39.06 | 36.27 | 33.85 | 36.80 | 36.25 | 34.24 | 32.44 | 30.81
Price Total | 507.72 | 226.60 | 226.60 | 226.60 | 226.60 | 246.60 | 319.69 | 319.69 | 327.68 | 355.17 | 355.17 | 487.72 | 487.72 | 507.72 | 507.72 | 507.72 | 588.80 | 616.29 | 616.29 | 616.29 | 616.29

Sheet: BOM_2024_Workshop_Austria
Number | Group | Component | Image | Description | Price (per Package) | Quantity (In Package) | Pro Boot Benötigt | Price (Per Boat) | Quantity (min Packages) | Price (Total) | Link | Alternative | Alternative 2 | Alternative 3 | Check
1.1 | 1 Brain | Microcontroller | #VALUE! | Wemos D1 Mini | 18.99 | 5 | 1 | 3.80 | 3 | 56.97 | https://amzn.eu/d/8o4qvAL |  |  |  | x
2.1 | 2 Propulsion System | Motor Driver | #VALUE! | DRV8833, 1.5 A | 5.99 | 5 | 1 | 1.20 | 3 | 17.97 | https://amzn.eu/d/gTUUtYN |  |  |  | x
2.2 | 2 Propulsion System | Motor | #VALUE! | 7x20 mm coreless DC Motor, 55 mm Propeller (7x16 mm would be even better) | 14.99 | 10 | 2 | 3.00 | 3 | 44.97 | https://amzn.eu/d/8jy2FVU |  |  | x | x
2.3 | 2 Propulsion System | Propeller |  |  | 7.49 | 16 | 2 | 0.94 | 2 | 14.98 | https://amzn.eu/d/e5wDtpY |  |  |  | x
3.1 | 3 Power Supply | Switch | #VALUE! | 3 A Mini Switch | 12.99 | 10 | 1 | 1.30 | 2 | 25.98 | https://amzn.eu/d/4KCSOd2 | https://amzn.eu/d/gmiQ5nL | https://amzn.eu/d/7L0AFRe | x | x
3.2 | 3 Power Supply | Step Up Converter | #VALUE! | to 5 V 1 A | 7.49 | 10 | 2 | 1.50 | 3 | 22.47 | https://amzn.eu/d/hQ5Fipr |  |  |  | x
3.3 | 3 Power Supply | BMS + Battery Holder | #VALUE! | Micro USB Port, TP4056 Chip, Charging and Protection | 8 | 10 | 1 | 0.80 | 2 | 16 | https://amzn.eu/d/i4H2p2R |  |  |  | x
3.4 | 3 Power Supply | Battery | #VALUE! | 18650 Li-Ion | 17.09 | 5 | 1 | 3.42 | 3 | 51.27 | https://amzn.eu/d/8rUZ3UA |  |  |  | x
4.1 | 4 Connection Equiptment | Wire flex | #VALUE! | 0,5 mm flex | 15.99 | 10 | 1 | 1.60 | 2 | 31.98 | https://amzn.eu/d/6LyUK9p |  |  | 1 | x nur 1
4.2 | 4 Connection Equiptment | Wire solid | #VALUE! | AWG 22 1 core | 7.99 | 10 | 1 | 0.80 | 2 | 15.98 | https://amzn.eu/d/hEwwOHh |  |  |  | x
4.3 | 4 Connection Equiptment | Pin Headers | #VALUE! | 2,54 mm | 7.79 | 50 | 2 | 0.31 | 1 | 7.79 | https://amzn.eu/d/a8is0Px |  |  |  | x
4.4 | 4 Connection Equiptment | Shrink Tubing | #VALUE! | 3:1 1,5 to 0.5 mm | 9.5 | 1 | 0.1 | 0.95 | 2 | 19 | https://amzn.eu/d/3WeLk5l |  |  | 1 | x
4.5 | 4 Connection Equiptment | Breadboard | #VALUE! |  | 8.54 | 5 | 1 | 1.71 | 3 | 25.62 | https://amzn.eu/d/39lWZCQ |  |  |  | x
4.6 | 4 Connection Equiptment | Battery Connector | #VALUE! | JST SM-2 Male | 4.99 | 10 | 1 | 0.50 | 2 | 9.98 | https://amzn.eu/d/dPWls2S |  |  |  | x
5.1 | 5 Lights | RGB LED Strip | #VALUE! |  | 27.99 | 300 | 8 | 0.75 | 1 | 27.99 | https://amzn.eu/d/i4iAauW |  |  |  | x
7.1 | 7 3D Printed Parts | Filament | #VALUE! |  | 20 | 1000 | 250 | 5.00 | 4 | 80 | https://amzn.eu/d/aCX3FEc |  |  | 14,99 Angebot | x
8.1 | 8 Further Components | Motor Capacitor | #VALUE! | 10nF | 5.99 | 100 | 2 | 0.12 | 1 | 5.99 | https://amzn.eu/d/1UbT236 |  |  |  | x
8.2 | 8 Further Components | Big Capacitor | #VALUE! |  | 7.99 | 15 | 2 | 1.07 | 2 | 15.98 | https://amzn.eu/d/hKmvStG |  |  |  | x
8.3 | 8 Further Components | LED Resistor | #VALUE! | 470 Ohm 0,25 W | 5.69 | 50 | 1 | 0.11 | 1 | 5.69 | https://amzn.eu/d/bnOOZtQ |  |  |  | x
8.4 | 8 Further Components | Voltage Sensor Resistor | #VALUE! | 180 Kohm 0,25 W | 11.11 | 50 | 1 | 0.22 | 1 | 11.11 | https://amzn.eu/d/30379W4 |  |  |  | x

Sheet: Component Groups
Name | Number | Group
1 Brain | 1
2 Propulsion System | 2 | = [@Number] & " " & [@Name]
3 Power Supply | 3 | = [@Number] & " " & [@Name]
4 Connection Equiptment | 4 | = [@Number] & " " & [@Name]
5 Lights | 5 | = [@Number] & " " & [@Name]
6 Bottles | 6 | = [@Number] & " " & [@Name]
7 3D Printed Parts | 7 | = [@Number] & " " & [@Name]
8 Further Components | 8 | = [@Number] & " " & [@Name]

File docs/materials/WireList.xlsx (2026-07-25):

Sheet: Wires
Farbe | Anzahl | Länge (Löcher) | Länge (mm) | Total (mm)
black | 3 | 5 | 26.7 | 80.1
black | 2 | 4 | 24.16 | 48.32
red | 3 | 4 | 24.16 | 72.48
red | 2 | 5 | 26.7 | 53.4
yellow | 2 | 16 | 54.64 | 109.28
yellow | 2 | 18 | 59.72 | 119.44
yellow | 1 | 12 | 44.48 | 44.48
yellow | 1 | 17 | 57.18 | 57.18
 | 16 |  |  | 584.68

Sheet: Base Values
Stripping Length | 7 | mm
HoleDistnace | 2.54 | mm

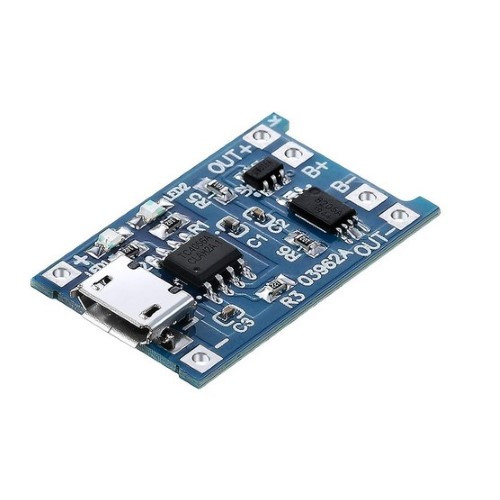
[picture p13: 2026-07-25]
docs/images/components/BMS_TP4065.jpg

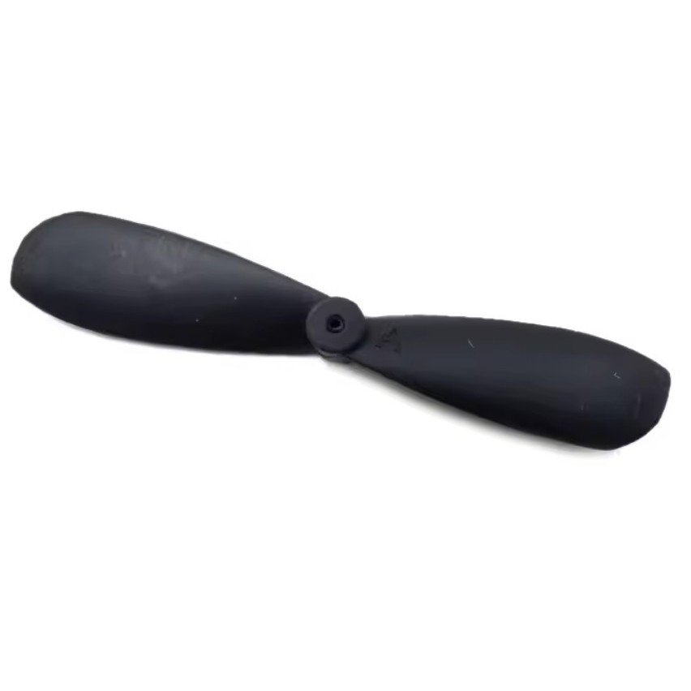
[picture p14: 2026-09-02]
docs/images/components/Propeller.jpg

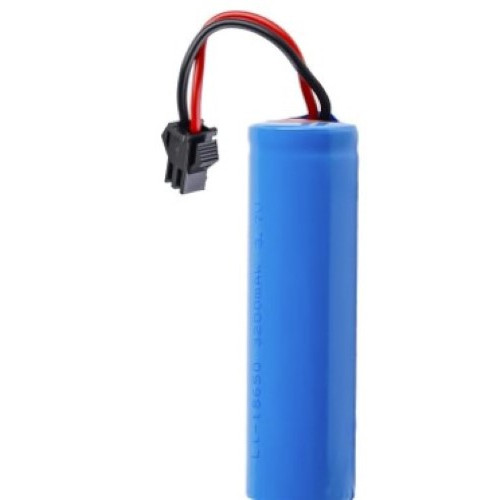
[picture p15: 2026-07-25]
docs/images/components/Battery_18650WithConnector.jpg

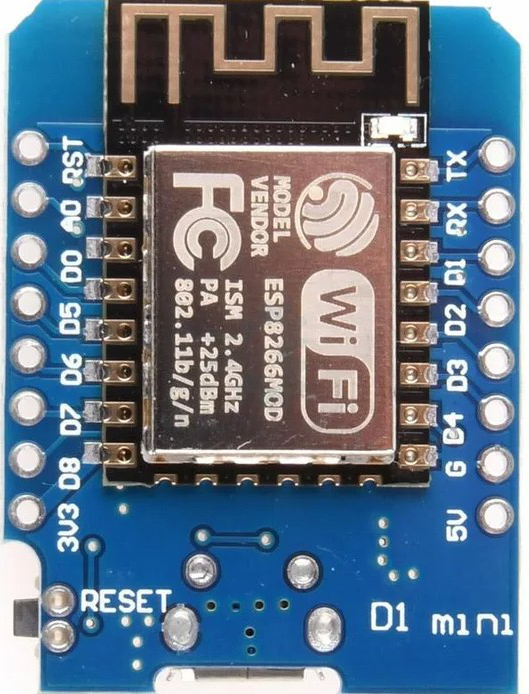
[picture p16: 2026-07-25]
docs/images/components/Microcontroller_WemosD1Mini_TopView.jpg

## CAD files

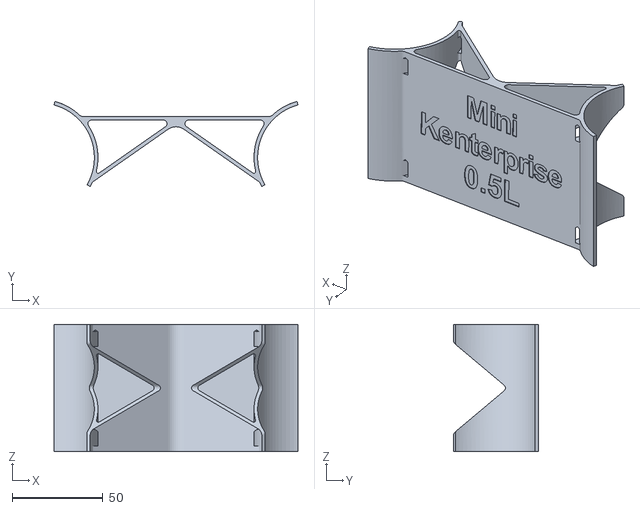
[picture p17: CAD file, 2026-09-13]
3dFiles/05l_Bottle/Bridge.stl
134.5 x 46.9 x 70.0

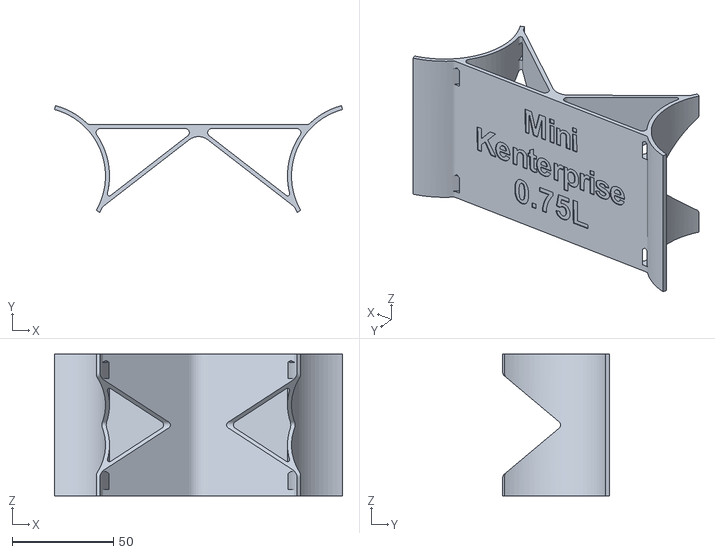
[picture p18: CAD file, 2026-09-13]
3dFiles/075l_Bottle/Bridge.stl
142.4 x 52.8 x 70.0

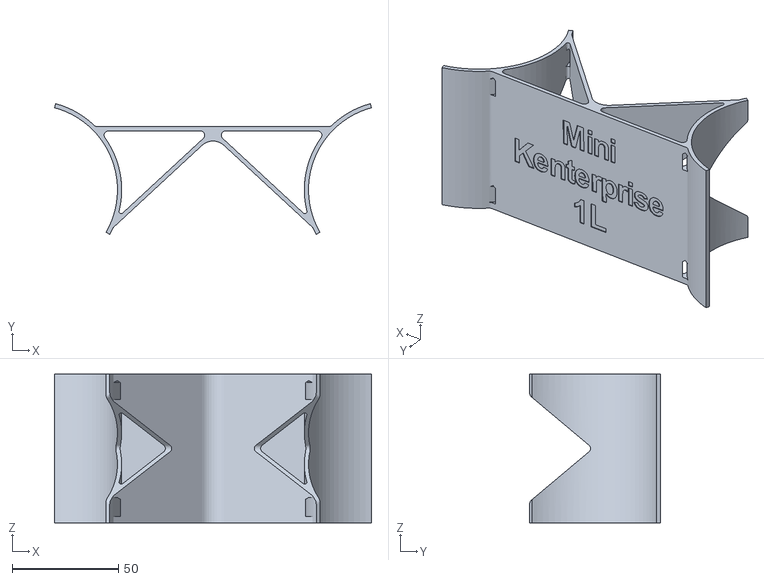
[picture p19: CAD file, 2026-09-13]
3dFiles/1l_Bottle/Bridge.stl
149.3 x 61.6 x 70.0

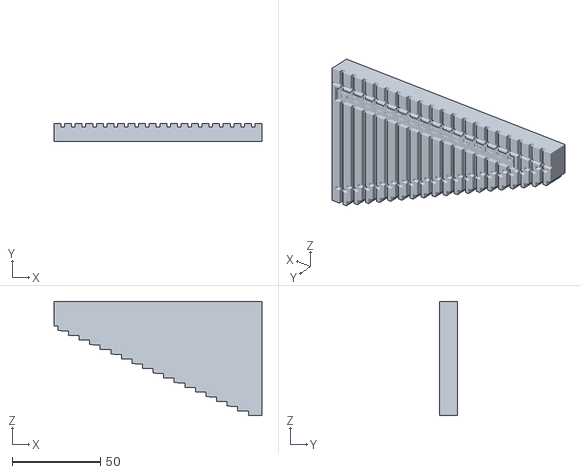
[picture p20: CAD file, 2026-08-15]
3dFiles/BendingHelp_20.stl
118.0 x 10.0 x 64.8

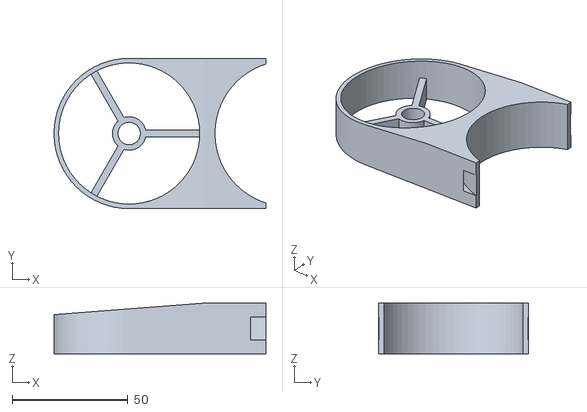
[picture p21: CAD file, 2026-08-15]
3dFiles/openscad/FanEnclosure.stl
91.7 x 65.0 x 22.0

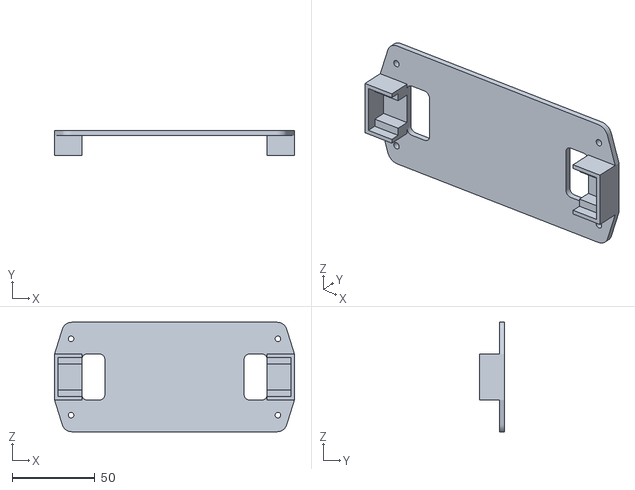
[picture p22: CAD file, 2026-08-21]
3dFiles/special/kevin/MiddlePlate.stl
144.6 x 15.0 x 66.0

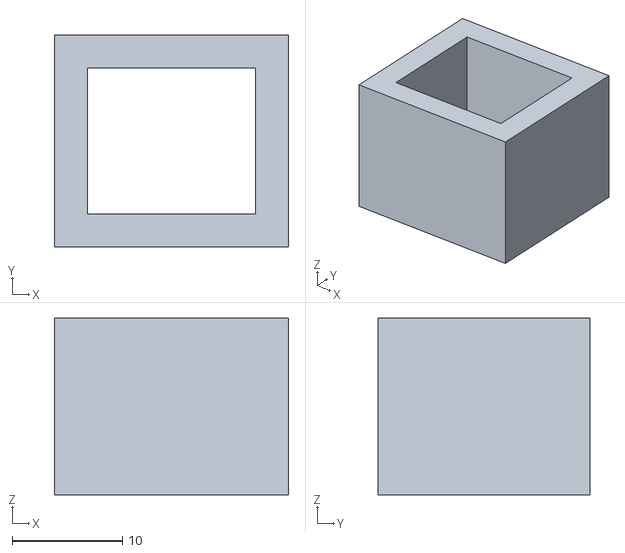
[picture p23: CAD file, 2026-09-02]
3dFiles/special/lego_boat/MotorMount.stl
21.2 x 19.2 x 16.0

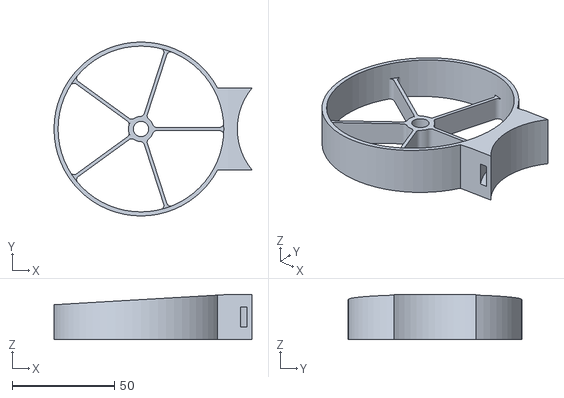
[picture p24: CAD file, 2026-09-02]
3dFiles/05l_Bottle/FanEnclosure_05L_M7_P75.stl
96.8 x 85.0 x 22.0

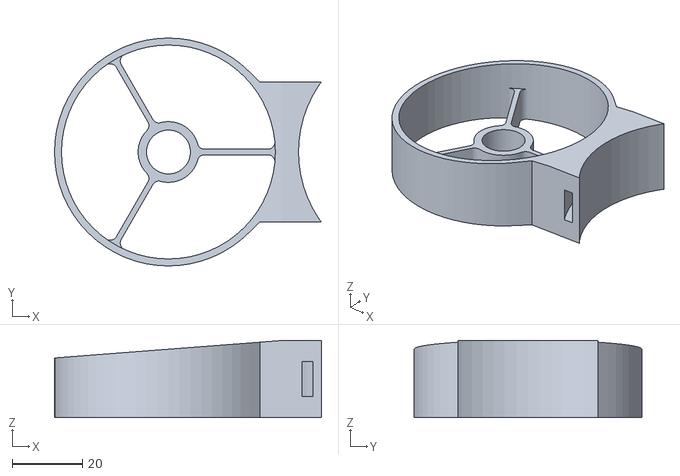
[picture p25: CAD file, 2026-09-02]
3dFiles/075l_Bottle/FanEnclosure_075L_M12_P55.stl
76.2 x 65.0 x 22.0

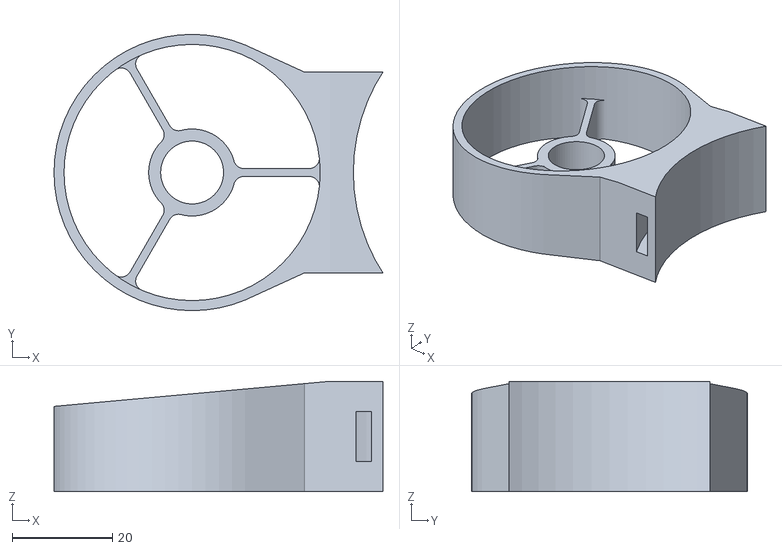
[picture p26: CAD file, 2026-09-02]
3dFiles/1l_Bottle/FanEnclosure_1L_M12_P45.stl
65.5 x 55.0 x 22.0

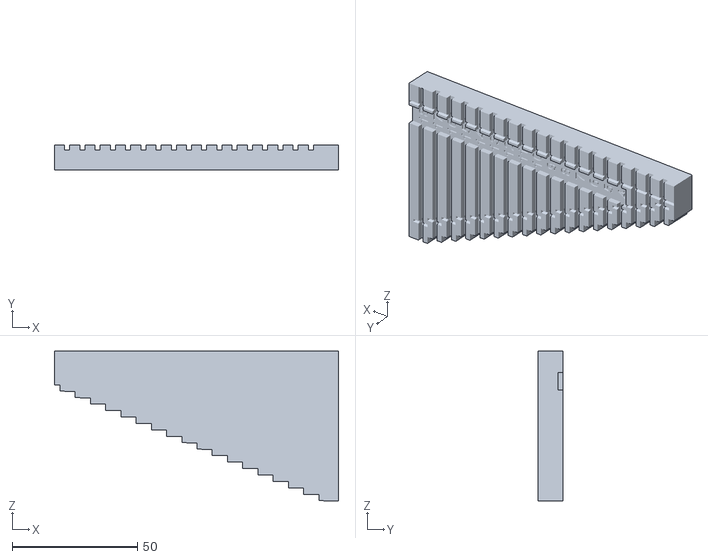
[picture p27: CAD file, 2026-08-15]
3dFiles/BendingHelp.stl
113.4 x 10.0 x 59.7

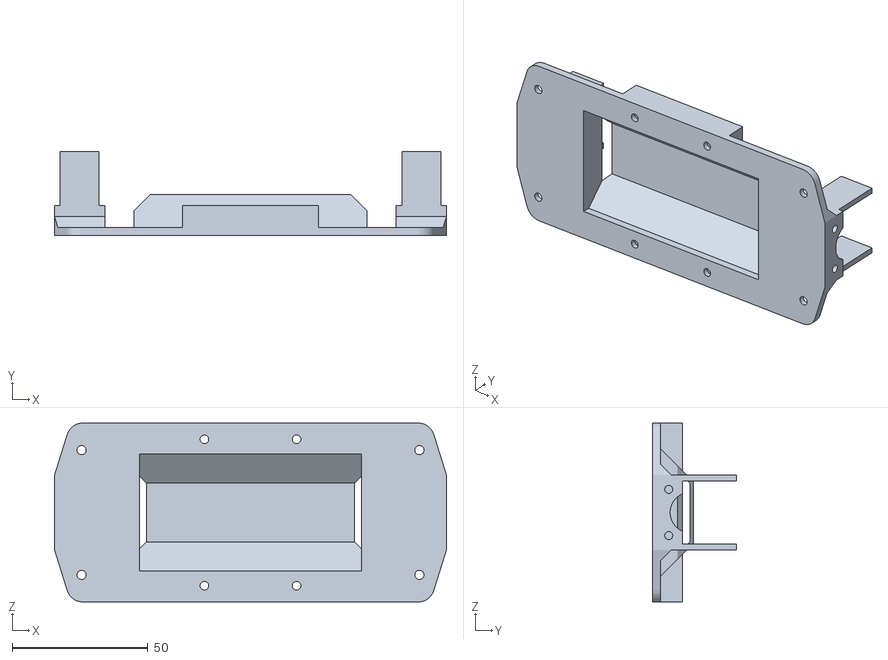
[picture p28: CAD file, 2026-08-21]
3dFiles/special/kevin/Baseplate.stl
144.6 x 31.0 x 66.0

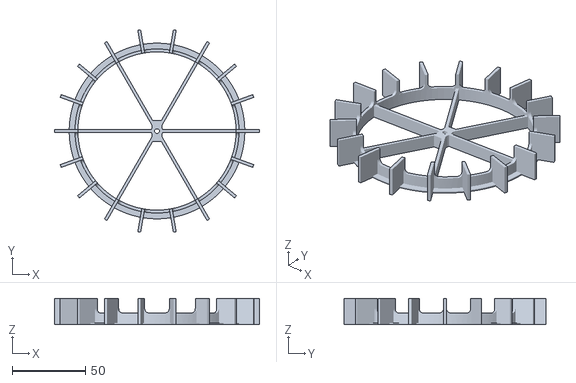
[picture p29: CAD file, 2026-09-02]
3dFiles/special/lego_boat/Waterwheel.stl
140.0 x 138.2 x 18.0

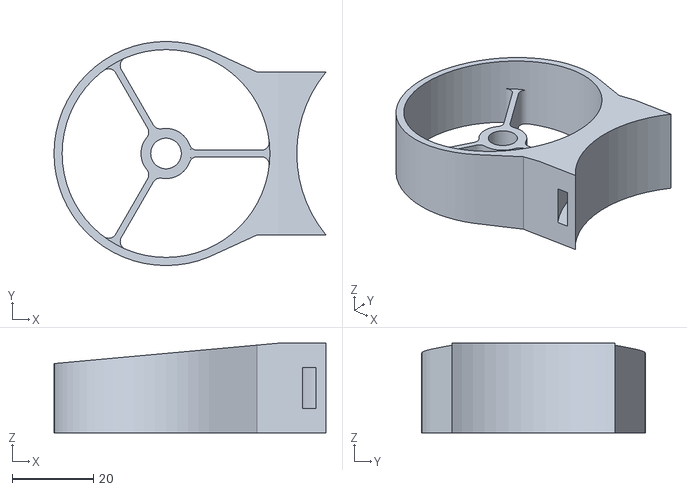
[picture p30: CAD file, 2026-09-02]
3dFiles/05l_Bottle/FanEnclosure_05L_M7_P45.stl
66.8 x 55.0 x 22.0

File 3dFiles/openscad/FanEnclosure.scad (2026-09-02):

/*
 * Parametric sketch of a fan enclosure: a motor hub, a propeller guard ring connected to
 * the hub by spokes, and a flat ziptie-mount tab.
 *
 * This is a rough structural sketch, NOT dimensionally matched to the existing hand-modeled
 * Fusion 360 parts in 3dFiles/ - the numbers below (wall thicknesses, tab size, hub height)
 * are guesses. Measure the real parts (calipers, or open one of the existing STLs) and
 * correct the defaults before trusting a print of this.
 *
 * Usage:
 *   Open directly in the OpenSCAD GUI to tweak parameters with the Customizer, or render
 *   headlessly with overrides, e.g.:
 *     openscad -o out.stl -D motorDiameter=8.5 -D propDiameter=55 -D bottleDiameter=63 FanEnclosure.scad
 */

// --- Parameters (override with -D on the CLI, or the Customizer in the GUI) ---

// Motor / propeller
motorDiameter = 8.5;    // mm - motor can diameter (from docs/materials/motorsAndProps.csv) (adjustable)
motorAxleLength = 6;
motorMountDepth = 10;   // mm - how far the motor is held/gripped by the hub
propDiameter = 55;      // mm - propeller diameter (adjustable)
bottleDiameter = 63;    // mm - bottle diameter near the neck, where the real mount actually sits
                        // (see note below) - PLACEHOLDER, measure per bottle size (adjustable)

// Hub and guard ring
hubClearance = 0.26;     // mm - extra radius so the motor is a friction/glue fit, not press-fit
hubWallThickness = 2.4; // mm
guardClearance = 3;     // mm - gap between prop tip and the inside of the guard ring
guardThickness = 2;     // mm - guard ring cross-section thickness

// Spokes connecting the hub to the guard ring
spokeWidth = 1.6;       // mm

// Mount tab: the bottom mount is cut by the bottle
tabThickness = 2;         // mm
zipTieSlotThickness = 2.6;
zipTieSlotLength = 10;

// Arm: the arm bridging the guard ring to the bottle tapers down from the
// full guard-ring width to a narrower, shorter foot near the bottle, via a
// smooth rounded taper (hull of two different-sized cylinders).
taperLength = 18;    // mm - length of the rounded taper from the ring down to the foot (adjustable)
footWidth = 40;      // mm - width of the straight foot section near the bottle (adjustable)

// Fillet: rounds off the sharp inside corners where the spokes meet the
// hub and the guard ring, for stress relief.
filletRadius = 2;    // mm - radius rounding off the spoke junctions (adjustable)

$fn = 64; // smoothness for circles/cylinders - lower for faster preview renders

// --- Derived dimensions ---

spokeCount = propDiameter > 55 ? 5 : 3;

minPartHeight = motorMountDepth + motorAxleLength + 1;
partHeight = minPartHeight + 5;

hubOuterRadius = motorDiameter / 2 + hubClearance + hubWallThickness;
guardInnerRadius = propDiameter / 2 + guardClearance;
guardOuterRadius = guardInnerRadius + guardThickness;

zipTieInnerRadius = bottleDiameter / 2 + 2;
zipTieOuterRadius = zipTieInnerRadius + zipTieSlotThickness;

armLength = guardOuterRadius + tabThickness + zipTieSlotThickness + bottleDiameter / 2;
footHalfWidth = footWidth / 2;
minFootLength = tabThickness + zipTieSlotThickness; // mm - always leave at least this much straight foot before the bottle cutout
taper = min(taperLength, armLength - minFootLength);

spokeLength = guardInnerRadius - hubOuterRadius + 1;
fillet = min(filletRadius, hubOuterRadius / 2, guardInnerRadius / 2); // clamp to something sane relative to the hub/ring

// --- Parts ---

module guard_ring() {
  difference() {
    cylinder(h = partHeight, r = guardOuterRadius);
    translate([0, 0, -1])
      cylinder(h = partHeight + 2, r = guardInnerRadius);
  }
}

function normAngle(a) = a < 0 ? a + 360 : a;
function shortSweep(a1, a2) =
  let(d = normAngle(a2) - normAngle(a1))
  d > 180 ? d - 360 : (d < -180 ? d + 360 : d);

// The exact circular fillet arc that rounds the concave corner where a
// flat spoke edge (the line y = side*spokeHalf) meets a circle of the
// given radius centered on the origin - built as an explicit polygon
// (vertex -> fillet arc -> circle arc) rather than a boolean trim, since
// offset()/intersection-based trims proved numerically unreliable on this
// shape. `outside` picks which side of that circle the fillet sits on:
// true for a fillet bulging out from a solid disk (the hub), false for one
// tucked just inside a bore (the guard ring's inner surface).
module concave_fillet(circleRadius, spokeHalf, filletR, side, outside, segs = 16) {
  cy = side * (spokeHalf + filletR);
  d = outside ? circleRadius + filletR : circleRadius - filletR;
  cx = sqrt(max(d * d - cy * cy, 0));

  vx = sqrt(max(circleRadius * circleRadius - spokeHalf * spokeHalf, 0));
  vy = side * spokeHalf;

  angleToCenter = atan2(cy, cx);
  ctx = circleRadius * cos(angleToCenter);
  cty = circleRadius * sin(angleToCenter);

  angLine = atan2(-side * filletR, 0); // the line-tangent point sits directly below/above the fillet center
  angCircle = atan2(cty - cy, ctx - cx);
  sweep1 = shortSweep(angLine, angCircle);
  arcPoints = [for (i = [0 : segs])
    let(a = angLine + sweep1 * i / segs)
    [cx + filletR * cos(a), cy + filletR * sin(a)]
  ];

  angVertexOnCircle = atan2(vy, vx);
  angTangentOnCircle = atan2(cty, ctx);
  sweep2 = shortSweep(angTangentOnCircle, angVertexOnCircle);
  circleArcPoints = [for (i = [0 : segs])
    let(a = angTangentOnCircle + sweep2 * i / segs)
    [circleRadius * cos(a), circleRadius * sin(a)]
  ];

  polygon(points = concat([[vx, vy]], arcPoints, circleArcPoints));
}

// A spoke with a true rounded fillet at each of its four corners: two
// where it meets the hub, two where it meets the guard ring's inner
// surface.
module spoke() {
  spokeHalf = spokeWidth / 2;
  union() {
    translate([hubOuterRadius - 0.5, -spokeHalf])
      square([spokeLength, spokeWidth]);
    concave_fillet(hubOuterRadius, spokeHalf, fillet, 1, true);
    concave_fillet(hubOuterRadius, spokeHalf, fillet, -1, true);
    concave_fillet(guardInnerRadius, spokeHalf, fillet, 1, false);
    concave_fillet(guardInnerRadius, spokeHalf, fillet, -1, false);
  }
}

module hub_and_spokes() {
  difference() {
    linear_extrude(height = motorMountDepth)
      union() {
        circle(r = hubOuterRadius);
        for (i = [0 : spokeCount - 1])
          rotate([0, 0, i * 360 / spokeCount])
            spoke();
      }
    translate([0, 0, -1])
      cylinder(h = motorMountDepth + tabThickness, r = motorDiameter / 2 + hubClearance);
  }
}

// The arm bridging the guard ring to the bottle mount: a smooth taper
// (hull of two different-sized cylinders) from the full guard-ring width
// down to a narrower foot, then a straight run out to the bottle cutout.
module mounting_arm() {
  difference() {
    union() {
      hull() {
        cylinder(h = partHeight, r = guardOuterRadius);
        translate([taper, 0, 0])
          cylinder(h = partHeight, r = footHalfWidth);
      }
      translate([taper, -footHalfWidth, 0])
        cube([armLength - taper, 2 * footHalfWidth, partHeight]);
    }
    translate([armLength, 0, -1])
      cylinder(h = partHeight + 2, r = bottleDiameter / 2);
    translate([0, 0, -1])
      cylinder(h = partHeight + 2, r = guardInnerRadius);
  }
}

// --- Cutters ---

// Trims the top of the assembly down to a shallow slope instead of a flat
// top, so the ring/arm taper from partHeight (at one side) to minPartHeight
// (at the other).
module slant_cutter() {
  angle = atan((partHeight - minPartHeight) / (2 * guardOuterRadius));
  translate([-guardOuterRadius, guardOuterRadius, minPartHeight])
    rotate([angle, 0, 270])
      cube([guardOuterRadius * 2, guardOuterRadius * 4, guardOuterRadius * 2]);
}

module bottom_cutter() {
  cutDistance = (bottleDiameter / 2) * 0.3;
  translate([armLength - cutDistance, -guardOuterRadius, 0])
    cube([(bottleDiameter / 2) * 0.5, guardOuterRadius * 2, partHeight]);
}

module ziptie_ring() {
  translate([armLength, 0, (partHeight - zipTieSlotLength) / 2])
    difference() {
      cylinder(h = zipTieSlotLength, r = zipTieOuterRadius);
      translate([0, 0, -1])
        cylinder(h = zipTieSlotLength + 2, r = zipTieInnerRadius);
    }
}

// --- Debug helpers ---

// Reference bottle, for checking the mounting arm's fit - not part of the
// printed model. Uncomment the call in fan_enclosure() to show it.
module bottle() {
  color([0.2, 0.5, 0.8])
    translate([armLength, 0, 0])
      cylinder(h = partHeight * 1.5, r = bottleDiameter / 2);
}

// --- Assembly ---

module fan_enclosure() {
  difference() {
    union() {
      hub_and_spokes();
      guard_ring();
      mounting_arm();
    }
    slant_cutter();
    ziptie_ring();
    bottom_cutter();
  }
  //bottle();
}

fan_enclosure();

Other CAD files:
3dFiles/075l_Bottle/FanEnclosure_075L_M7_P45.stl
3dFiles/1l_Bottle/FanEnclosure_1L_M7_P45.stl
3dFiles/special/kevin/top.stl
3dFiles/05l_Bottle/FanEnclosure_05L_M12_P75.stl
3dFiles/05l_Bottle/CenterPiece.stl
3dFiles/05l_Bottle/CenterPiece_ZiptieHoles.stl
3dFiles/05l_Bottle/FanEnclosure.stl
3dFiles/05l_Bottle/FanEnclosure55mm.stl
3dFiles/05l_Bottle/FanEnclosure_05L_M12_P45.stl
3dFiles/05l_Bottle/FanEnclosure_05L_M12_P55.stl
3dFiles/05l_Bottle/FanEnclosure_05L_M7_P55.stl
3dFiles/05l_Bottle/FanEnclosure_05L_M8-5_P45.stl
3dFiles/05l_Bottle/FanEnclosure_05L_M8-5_P55.stl
3dFiles/05l_Bottle/FanEnclosure_05L_M8-5_P75.stl
3dFiles/05l_Bottle/FanEnclosure_M8520_P55.stl
3dFiles/05l_Bottle/FanHolder45mm.stl
3dFiles/075l_Bottle/FanEnclosure_075L_M12_P45.stl
3dFiles/075l_Bottle/FanEnclosure_075L_M12_P75.stl
3dFiles/075l_Bottle/FanEnclosure_075L_M7_P55.stl
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

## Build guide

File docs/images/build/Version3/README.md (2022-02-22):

# Mini Kenterprise Version 3
Optimised for speed with light 0.75l, strong 3.7V Motors, big fans and a very small electronics enclosure.
Suitable for intermediates.
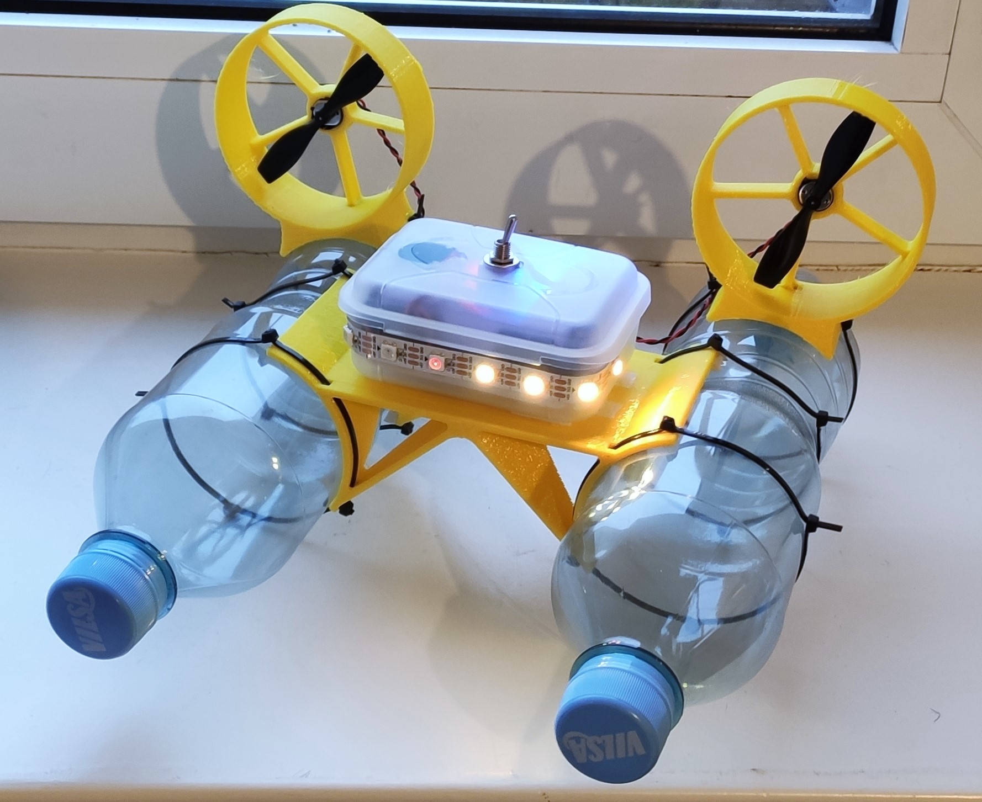
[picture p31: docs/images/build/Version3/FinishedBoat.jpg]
Boat

### Bill of Materials
Electronics to buy:
| Position | Component | Description | Quantity | Link |
|---|---|---|---|---|
| 1 | Breadboard | 400 dots | 1x | [Aliexpress](https://de.aliexpress.com/item/32711841420.html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) |
| 2 | Jumper Wires | stiff | 1x | [Aliexpress](https://de.aliexpress.com/item/1005002828254543.html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), [reichelt](https://www.reichelt.de/steckbruecken-drahtbruecken-set-140-teilig-steckboard-dbs-p79056.html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) |
| 3 | Pins |Male Pin Headers | 20x | [Aliexpress](https://de.aliexpress.com/item/32993182990.html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) |
| 4 | Battery | 18650 Li-Ion Cell | 1x | [AliExpress](https://de.aliexpress.com/item/1005003394481523.html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) |
| 5 | Battery Holder | 18650 Holder | 1x | [AliExpress](https://de.aliexpress.com/item/1005001769305908.html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) |
| 6 | Charger | TP4056 without protection | 1x | [Aliexpress](https://de.aliexpress.com/item/32467578996.html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)
| 7 | BMS | min. 3A Output | 1x | [Aliexpress](https://de.aliexpress.com/item/4001010955646.html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)
| 8 | Switch | 2 Pin Toggle Switch | 1x | [Aliexpress](https://de.aliexpress.com/item/32919390284.html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) |
| 9 | Voltage Booster | 5V 3A Boost | 1x | [Aliexpress](https://de.aliexpress.com/item/32789971588.html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,scm-url:1007.13339.169870.0,pvid:1cce7437-411f-4c78-8193-8489256c8459,tpp_buckets:668%232846%238112%231997&pdp_ext_f=%257B%2522sku_id%2522%253A%252263489306855%2522%252C%2522sceneId%2522%253A%25223339%2522%257D&pdp_pi=-1%253B1.06%253B-1%253B-1%2540salePrice%253BEUR%253Brecommend-recommend) |
| 11 | Motor Driver | DRV8833 Dual H-Bridge | 1x | [Aliexpress](https://de.aliexpress.com/item/4000083406292.html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) |
| 12 | Motor | M20 3.7V min DC Motor, 12mm diameter, 1mm shaft  | 2x | [Aliexpress](https://de.aliexpress.com/item/4000440406820.html?gatewayAdapt=glo2deu&spm=a2g0o.order_list.0.0.21ef5c5fz7fggi) |
| 13 | Peopeller | 1mm hole, 76mm diameter | 2x | [Aliexpress](https://de.aliexpress.com/item/1005003314629873.html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) | 
| 14 | Microcontroller | Wemos D1 Mini | 1x | [Aliexpress](https://de.aliexpress.com/item/32831353752.html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) |
| 15 | RGB LED | Neopixel WS2812b strip (60LEDs/m) | 6x | [Aliexpress](https://de.aliexpress.com/item/4000148759042.html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) |
| 16 | Resistor | 180 kOhm | 1x | [Aliexpress](https://de.aliexpress.com/item/1005002540879857.html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) |

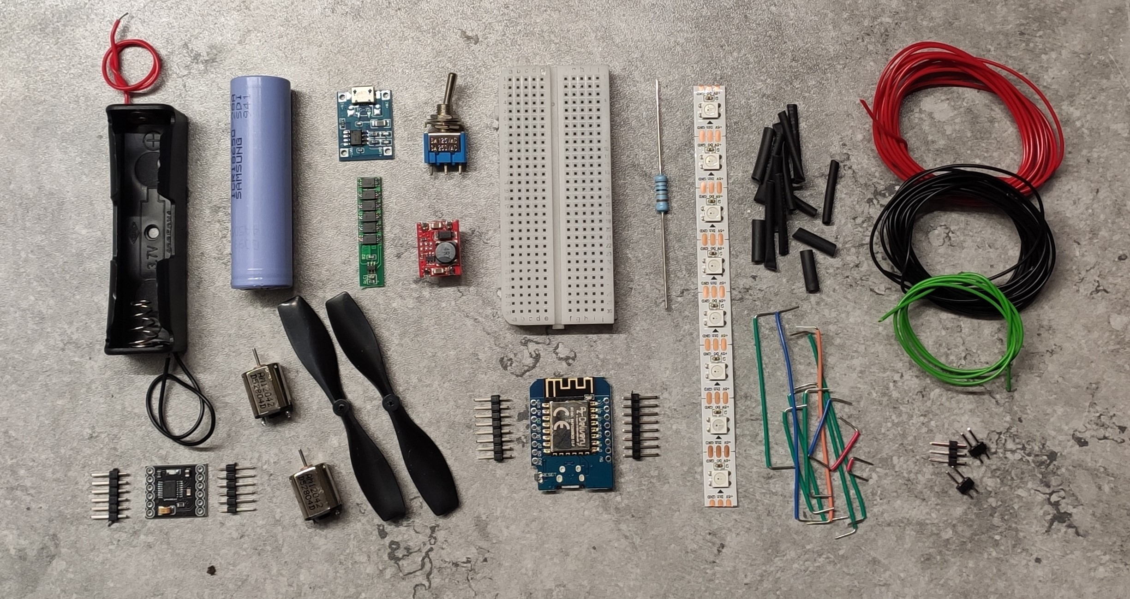
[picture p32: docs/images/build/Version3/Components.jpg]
Components


Further Components..
| Position | Component | Description | Quantity | Link |
|---|---|---|---|---|
| 1 | Bottle | hard plastic 1l (eg. Coke, Sprite, ...) | 2x | |
| 2 | Centerpiece | 3D printed electronics enclosure | 1x | |
| 3 | Fan Holder | 3D printed | 2x | |
| 4 | Mini Lunch Box | Plastic Container | 1x | |
| 5 | Ziptie | 200mm long, 4.3mm wide | 6x | |

### Electronics Box
The schematic can be seen in the following image. It doesn't seem very different from the other versions. There is only minor changes.
The motors are directly connected to the battery voltage and a couple of the input pins for the motor driver are switched around.
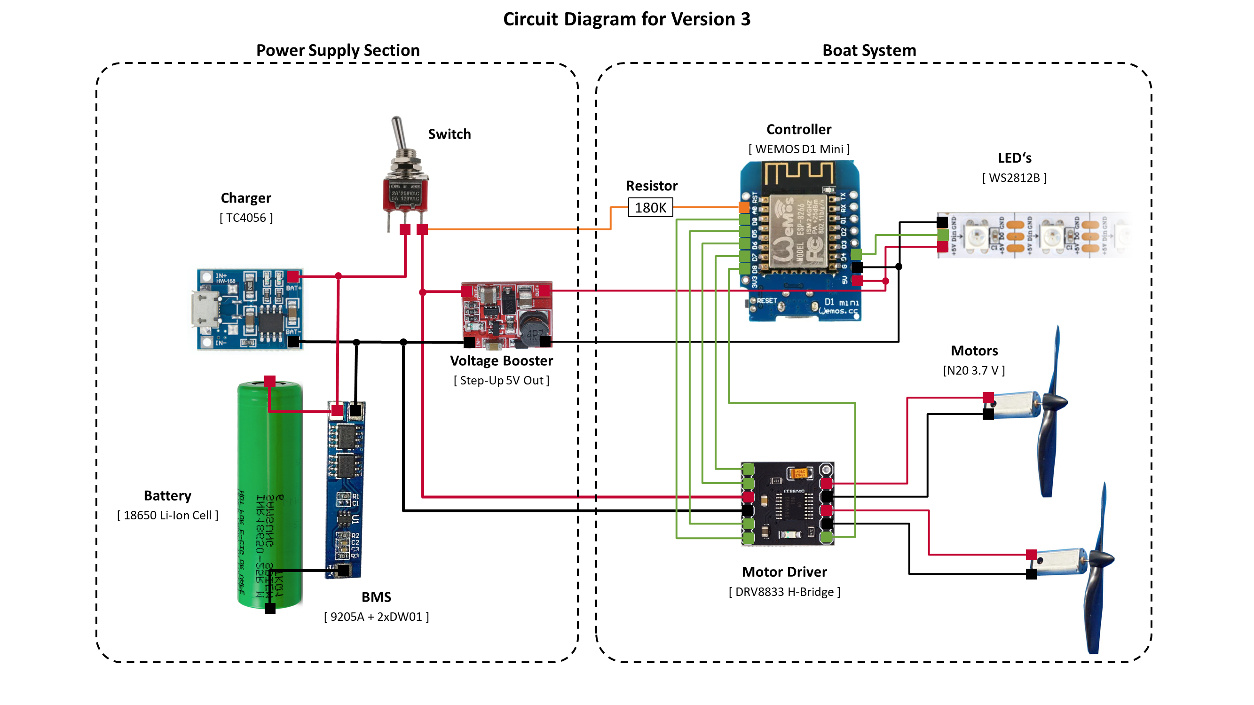
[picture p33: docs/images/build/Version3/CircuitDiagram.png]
Schematic

Physically this circuit diagram is translated into a very cramed little electronics boy that can be seen here.
The Electronics Box is particularly small with this version and the battery is located next to the breadboard.
Due to this the power rails of the breadboard have to be removed and the corners of it have to be filed down.
A 3D-printed electronics adapter is used to hold the BMS board in place and route the wires.
The charger and the switch are attached to the top of the enclosure.
As there are no power rails and the space is limited, there is a lot of breadboard connections.
Almost all of them follow along the center line of the breadboard in order to keep the sides free for the external connectors.
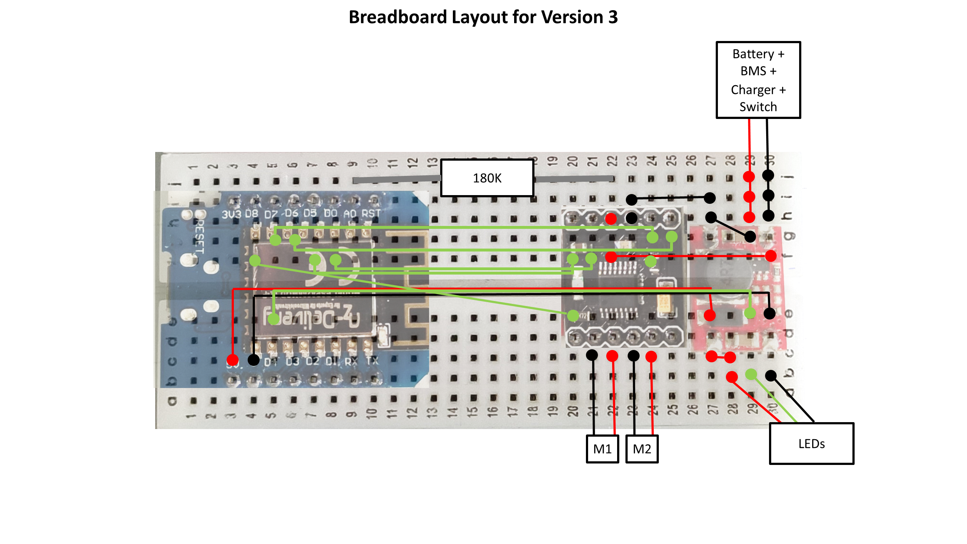
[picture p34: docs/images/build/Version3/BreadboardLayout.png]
Breadboard Layout

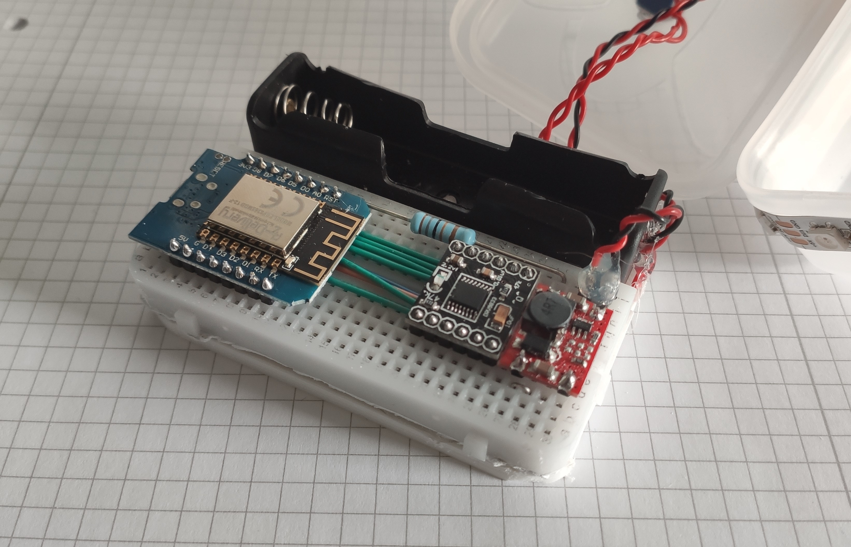
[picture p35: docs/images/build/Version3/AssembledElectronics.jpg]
Assembled Electronics

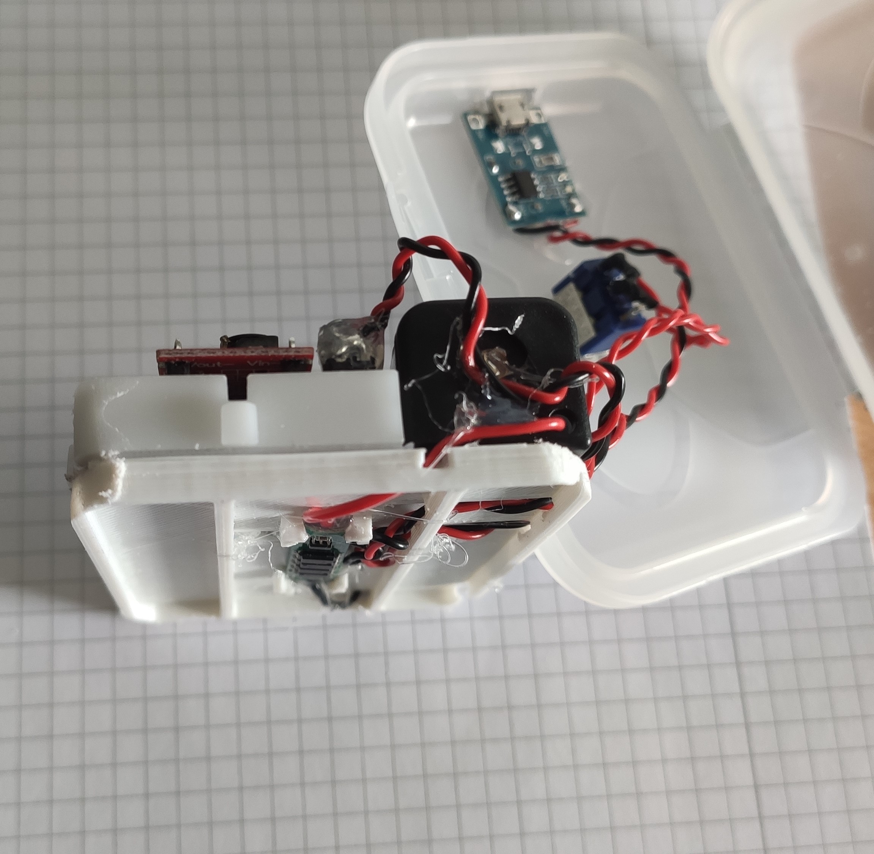
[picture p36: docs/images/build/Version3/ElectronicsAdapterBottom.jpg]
Adapter

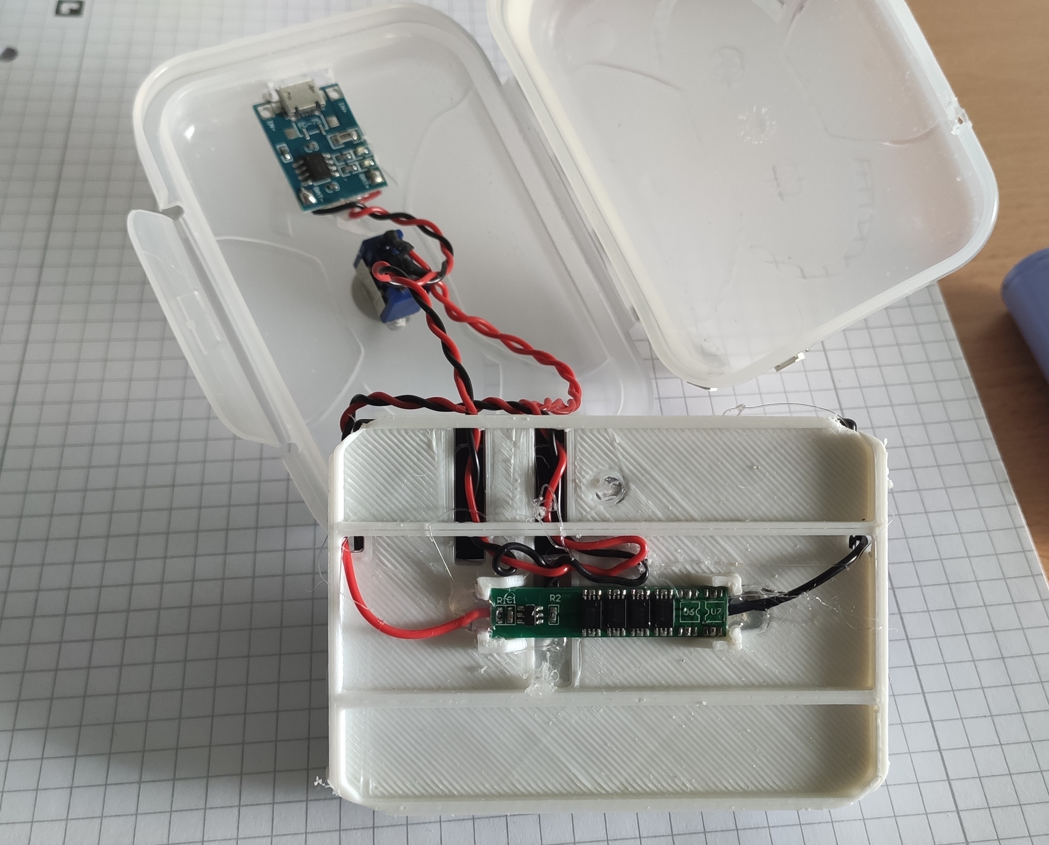
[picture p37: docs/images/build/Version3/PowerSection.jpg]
Adapter2

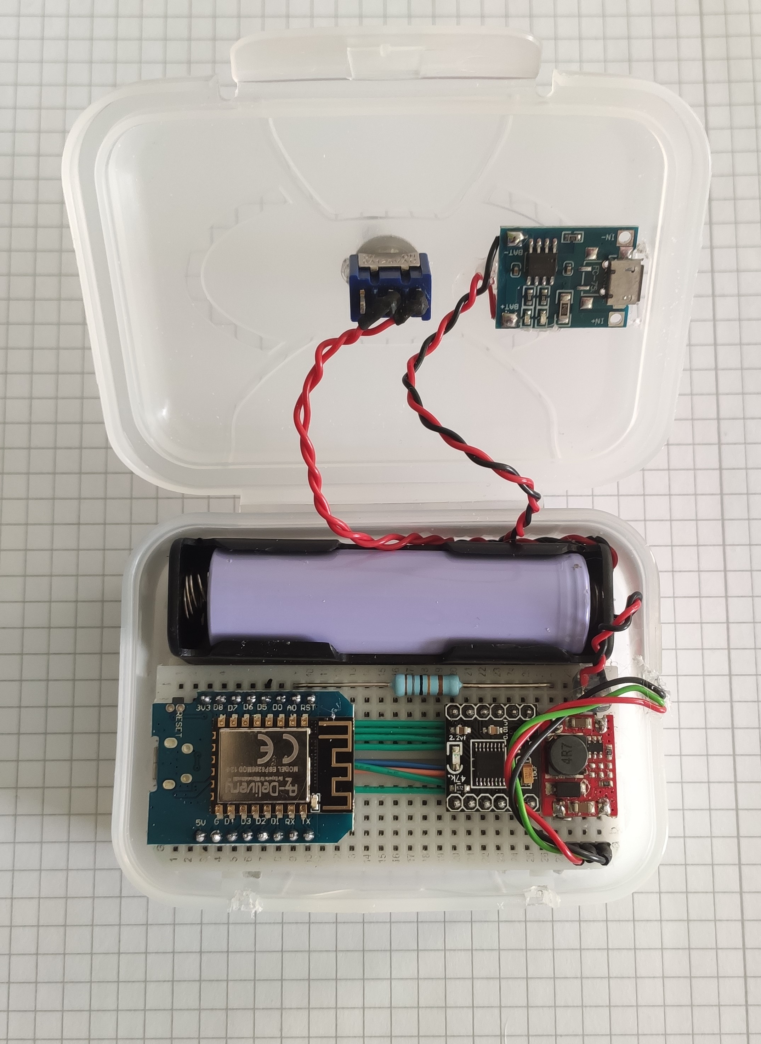
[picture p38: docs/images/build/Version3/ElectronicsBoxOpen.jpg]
Electronicsbox


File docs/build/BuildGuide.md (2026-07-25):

# Build Guide

This guide is being rewritten to follow the **Vorarlberg workshop setup** (0.5L bottle, DRV8833
driver, 720 motor, 55mm prop) - the current recommended starting point.

In the meantime:

- The [bill of materials](../materials/BOM.md) and the [Configurator](../configure.html) already
  cover the Vorarlberg setup and every other supported combination.
- Building the older 1L Wilhelmshaven setup instead (not reccommended)? See the
  [archived Wilhelmshaven build guide](./?guide=wilhelmshaven).

### 1. Get the electronics
Below you can see a picture of the electronics required to build a Mini Kenterprise.
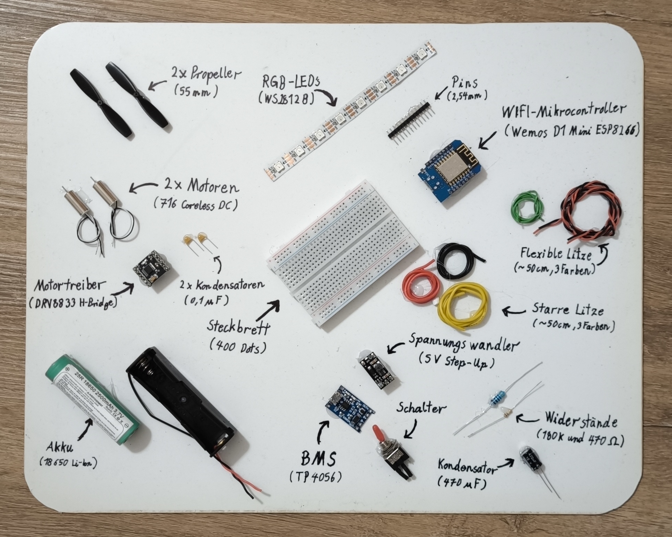
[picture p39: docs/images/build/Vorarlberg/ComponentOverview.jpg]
Components

The exact parts might change, depending on availability and i am trying to keep an updated document with the bill of materials in the configurator. The cost of building a Mini Kenterprise in Germany are currently (2024) around 35€.
The configurator will also give you the correct 3D files to download for printing.

#### 1.1 Customizing( Optional )
Keep in mind that sometimes you might not be able to get exactly the right motor or exactly the right propeller. For these cases, I built the configurator and provided you with a bunch of different 3D file versions. Simply configure the build with your motor and prop and you will get an appropriate fan enclosure part.

### 2. Find and prepare 2 bottles
The biggest componente of a Mini Kenterprise are the two plastic bottles that help it to stay afloat. It is important that the bottles have thick plastic walls. These make the boat more rigid. Thin bottles tend to heavily deform when they are closed off and the temperature changes.
I like to use coke or sprite bottles, as they have thick and straight walls. Most manufacturers tend to give their bottles all kinds of funky shapes. Unfortunateley those funky shapes make it hard to connect them to the 3D printed components.
The size of bottle that you want to use is up to you. 0.5 liter bottles make for a small and fast boat. 1L bootles make the boat slower, as they are pretty heavy, but the also make it more stable and allow for a payload (maybe a sensor) to be carried.
I found 0.75L bottles to be a great middle ground.
Make sure to remove the label, so it doesn't peel of in the water. You can do that by filling the bottle with warm water. This liquifies the adhesive.Also try to remove any water from the inside with a paper towel and a long spoon.
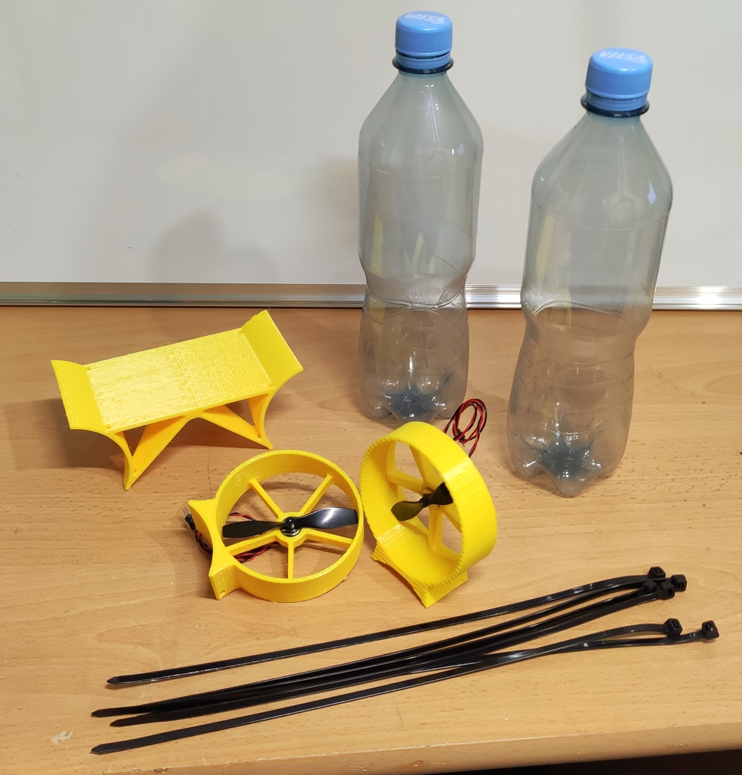
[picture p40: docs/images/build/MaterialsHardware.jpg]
Printing


### 3. Print the bridge and the fan enclosures
Apart from the bottles, there is a center piece called the bridege and two motor holders. These parts are made in a 3D printer. You can get the STL files under [`/3dFiles`](../../3dFiles).
Make sure to choose the right version for your motor and fan size 75mm(with 12mm motor) and your bottle size (0.5L or 0.75L).

Open them in the slicing software of your choice. [Cura](https://ultimaker.com/de/software/ultimaker-cura) is a good slicer for that.
It is best to print these parts out of PETG, as it is a very robust material, that doesn't deform on a hot summer day. Set the layer height to 0.4 mm. The parts where designed for 3D printing and don't need any support. The two fan mounts have to be printed with the flat side laying on the printbed.
Start the slicing process and export the file to an SD card, a USB drive, whatever your 3D printer uses and start printing.

### 4. Assemble the electronics
While the print is in progress you can prepare the interesting part of the boat (coming from an electrical engineer :D), the electronics.
The circuit diagram shows how all of the parts have to be connected.
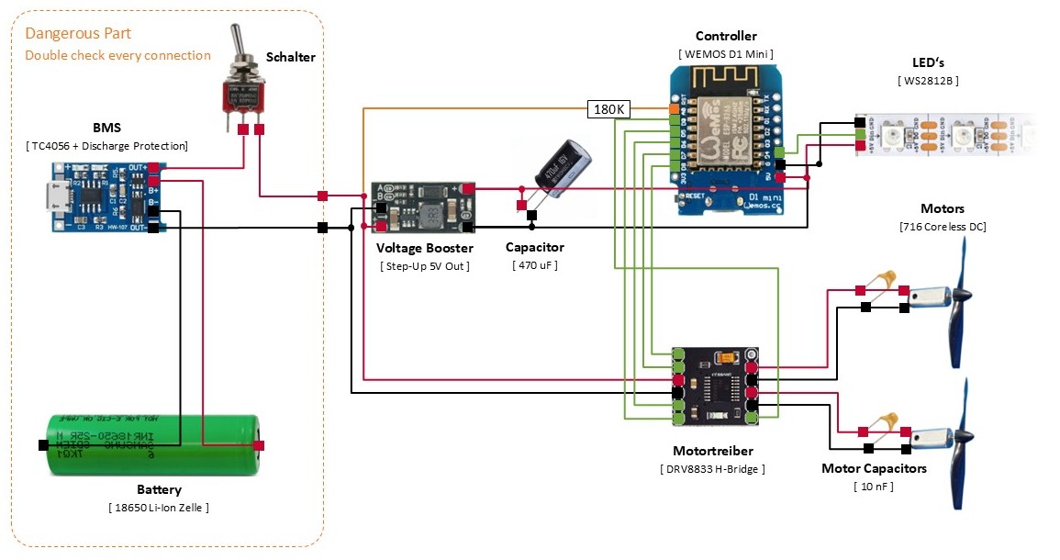
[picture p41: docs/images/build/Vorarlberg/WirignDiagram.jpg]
Wiring diagram
.

#### 4.1 Assemble the power supply section
The "power supply section" or in other words our selfmade powerbank should be assembled first. 
You can in theory put everything together on a breadboard. Howerver, I would not reccomend this when it comes to power supply components, as the potential to plug something in the wrong way and fry your whole circuit or even start a battery fire is quite big. Therefore all of the power supply components should be soldered togehter as seen in the following picture. If you are not using a battery with a connector, but a battery holder, you would also have the holder on there.
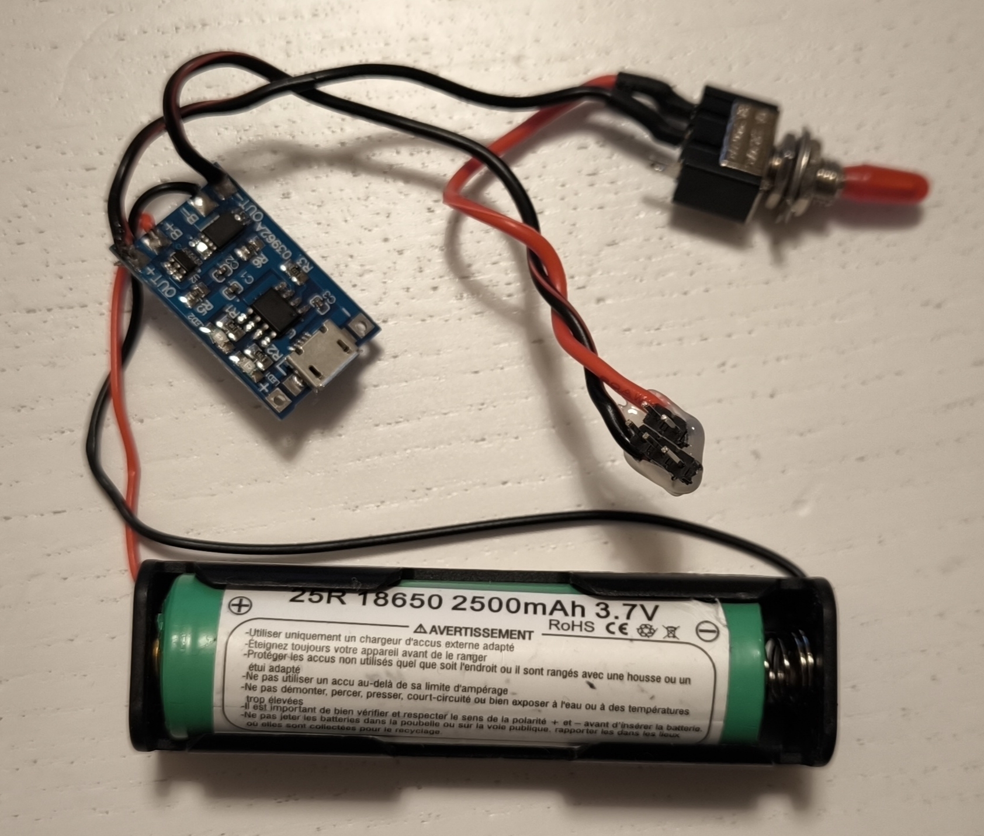
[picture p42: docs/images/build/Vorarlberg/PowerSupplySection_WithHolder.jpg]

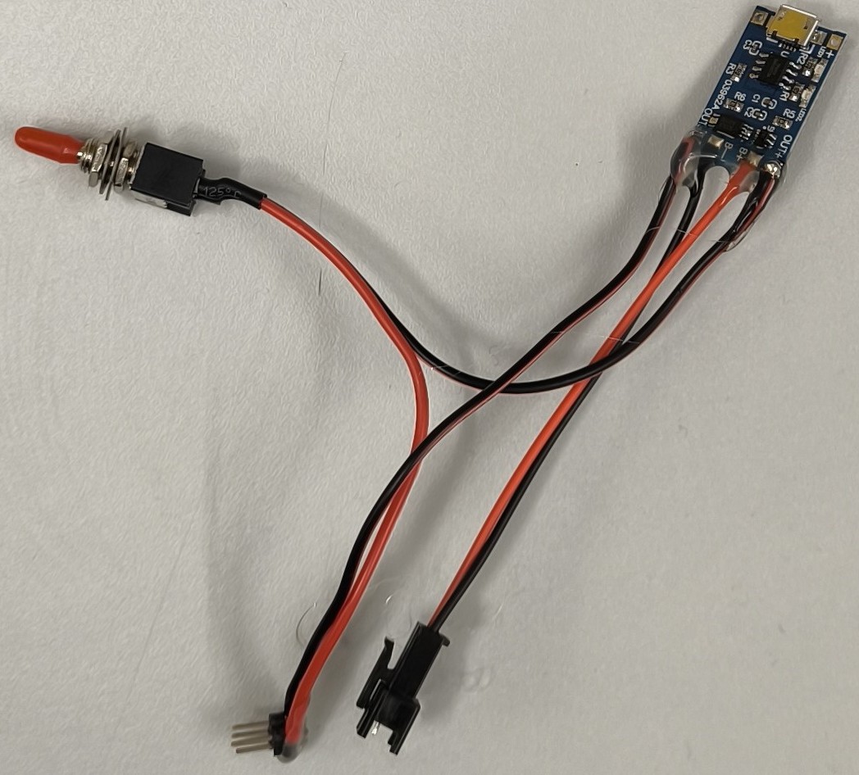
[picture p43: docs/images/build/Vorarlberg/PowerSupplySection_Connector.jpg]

Quick sidenote, you can also use an actual powerbank. But if you decide to use an of the shelf powerbank, the microcontroller will not be able to read the current battery voltage. Therefore the companion website can not tell you how much battery you have left.

#### 4.2 Solder Wires and Pins to further Components
The rest of the components will be plugged plugged together. A breadboard makes that possible without having to pull out the soldering ion every time. However, you will have to add so called "header pins" to your components, to be able to comfortably plug them into the breadboard.
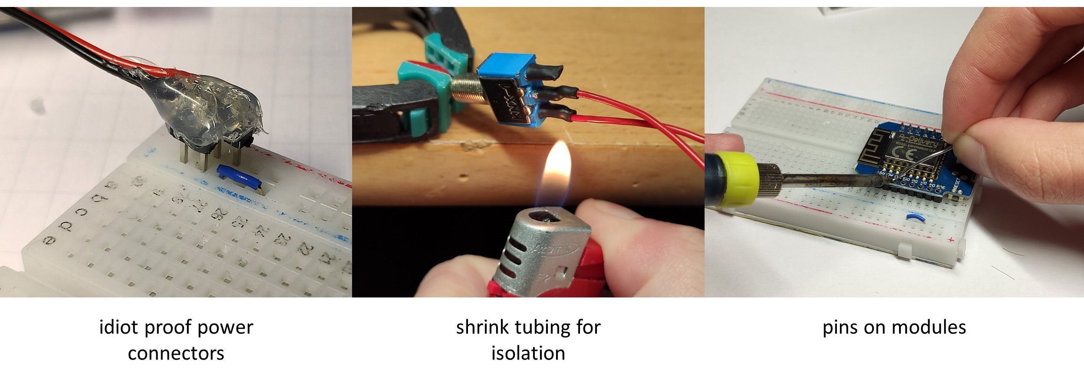
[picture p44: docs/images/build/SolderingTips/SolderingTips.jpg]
Soldering Tips

The best starting point for your soldering work are the modules, such as the microcontroller. Stick the pins into your breadboard and place the PCB (aka the board) on top.Then you can solder one pin at a time. Keep in mind to not heat anything up for too long (a few seconds not half a minute). The solder should flow nice and evenly and cover the metal rings on the board as well as your pins. A good soldering joint has an even surface.

The power supply connectors are probably the most important pins. These can be seen in the image below. I use three pins for each power rail. This way I inclrease the contact surface and make sure that it works, even if one pin is a little bit loose.
I also like to use a combination of 2 pins and 3 pins and block one hole in the breadboard, as shown in the picture.
This way i instantly know ho to plug it in. When there is two power rails, with two connectors, i make sure to remove one pin on each side, so i can not accidentially switch them around.

Most components, such as switches come without wires, so you will have to solder wires to them with. Be sure to tin the wire and the surface you want to solder to first.
To connect the two you then just have to hold them together and heat them up with the soldering ion before the tin connects them. Don't heat them up for too long, as the heat can melt the plastic bodies of the components.
Isolate each connection with some shrink tubing, hotglue or electrical tape.

#### 4.3 Assemble the Breadboard
When you are done soldering, you can simply plug everything into the breadboard.
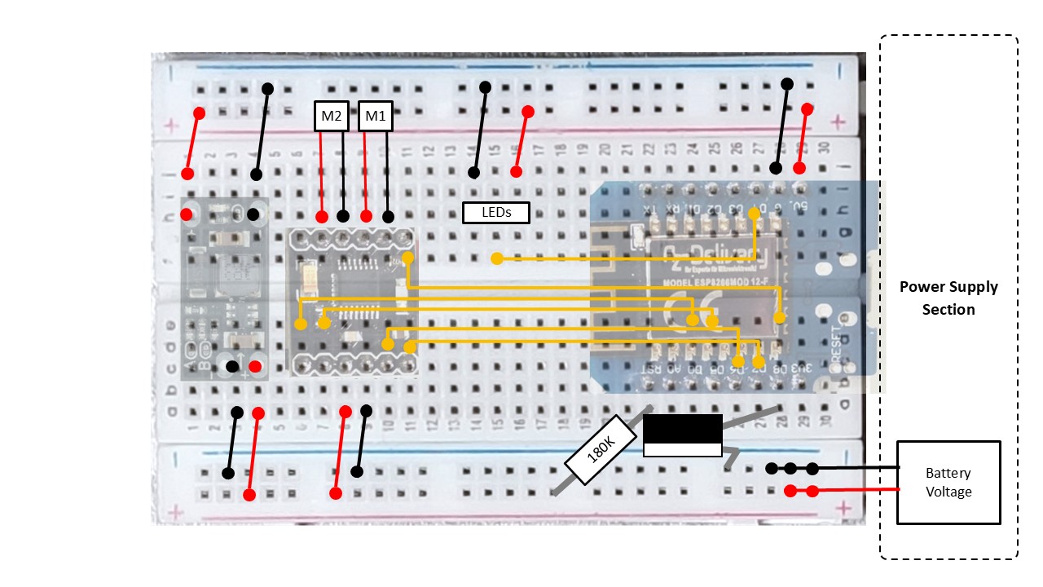
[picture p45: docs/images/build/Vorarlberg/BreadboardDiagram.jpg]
Breadboard

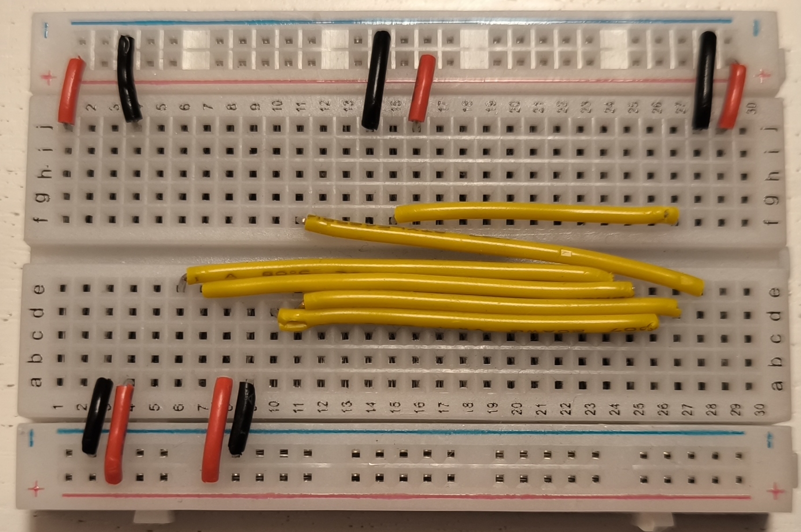
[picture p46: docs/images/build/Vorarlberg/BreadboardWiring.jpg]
Breadboard

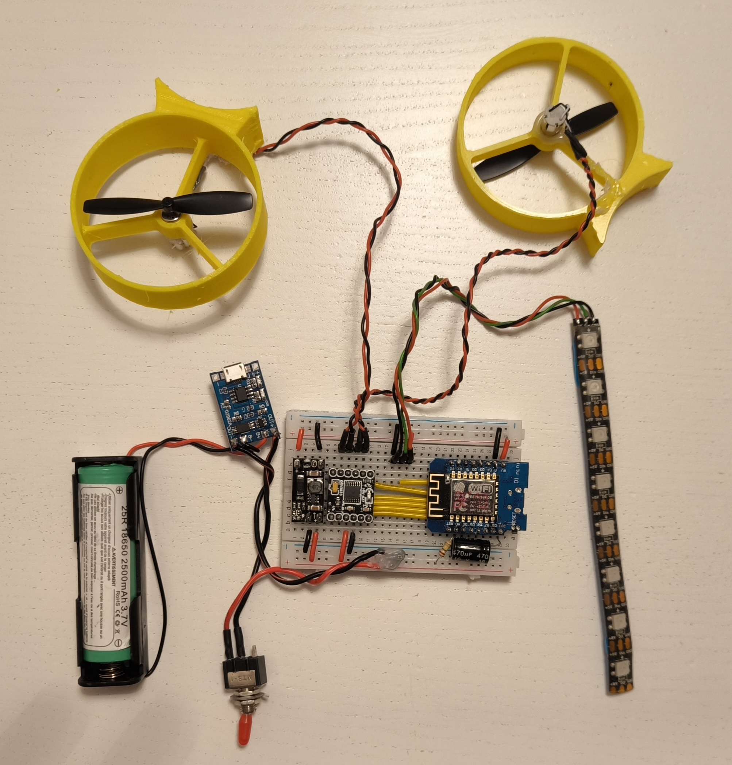
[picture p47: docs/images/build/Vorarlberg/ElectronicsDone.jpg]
FullyAssembled


### 5. CHECK YOUR CONNECTIONS and hook everything up
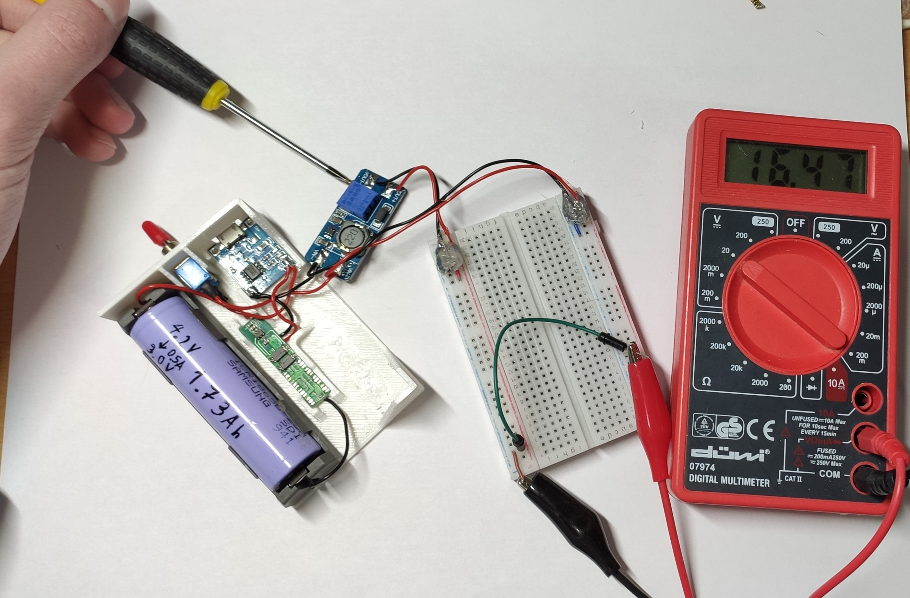
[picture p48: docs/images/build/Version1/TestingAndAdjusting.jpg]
Measuing


### 6. Program the microcontroller
No Arduino IDE required. Go to the [Mini Kenterprise flashing website](https://basementengineering.github.io/MiniKenterprise/), plug your boat's microcontroller into your PC via USB, and click the install button (works in Chrome or Edge). That's it - the firmware, including the on-device Control UI, gets flashed straight from your browser.

If you'd rather build the firmware yourself (e.g. to modify it), the source lives under [`/MiniKenterpriseCode`](../../MiniKenterpriseCode), the on-device Control UI source under [`/minikenterprise_frontend`](../../minikenterprise_frontend), and `deployFrontend.ps1` (repo root) rebuilds the Control UI and regenerates the headers the firmware embeds it from. See [`docs/DEVELOPMENT.md`](../DEVELOPMENT.md) for the full local development workflow (frontend dev server, testing, firmware upload, running the site locally).

### 7. Put the boat into operation
After being turned on the boat acts as a WiFi Access Point that devices can connect to.
Take your phone and search for the WiFi Network. By default this is called `MiniKenterprise_1` (password `RowYourBoat`) - you can change both, along with the pin assignments, from the boat's settings page at any time.
After you are connected to the WiFi your phone is probably going to tell you that the network has no internet connection and reccomend to change networks.
Sometimes the phone even switches to another network or to mobile automatically. Make sure that you catch the popup message and tell your phone that it is ok to stay in this network.
Now you want to open a webbrowser and enter get to the controller website. This can be done by entering the IP address 1.2.3.4 into the browsers address field.
This will bring you to a little website that looks like this:
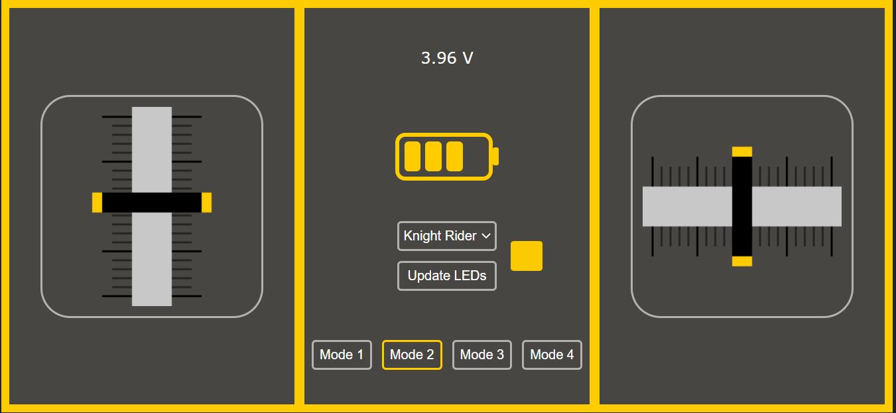
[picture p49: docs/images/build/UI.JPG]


#### 7.1 Configure the software
If you're building the version from this guide and follow the wiring setup, and you don't need a custom boat wifi name or want to connect to an existing network, the default will match your needs and no setup is required. If you built a different pin layout or want a different WiFi name/password, you can change those later from the boat's own settings page (see step 6) instead of editing any code.

#### 7.2 Adjust the motors
Time to confirm that the motors are working. Switch to mode 3 (buttons at the bottom).
Move the right stick all the way to the front. The right motor should start pushing air out the back. If the left motor starts spinning, you can simply switch the motor connectors around. If the motor pushes backwars, you can turn its connector around (switch + and  -).
Repeat the test for the left side.

### 8. Connect and charge the battery
Plug a Micro USB cable into the charging board. The LED should turn red, indicating that the battery is being charged. After 2 to 3 hours the LED will turn blue.

### 9. Use it
Now your boat is working properly and has a fully charged battery. Time to head to the lake.
Make sure that the weather is not too windy and not too rainy. It is also much more fun to play around in the sunshine.
Turn on your boat, connect your phone and take it for a spin on the water.
Try out the 4 different driving modes and figure out which one you like the most.
Keep an eye on the battery, if it consistently dips below 3.2V it is empty. If the voltage sinks too low, the BMS is going to disconnect the battery and leave your boat unmanouverable. Also make sure to stay in a range of about 20m and keep a long stick or a fishing line at hand, in case the boat gets stuck somewhere:D.
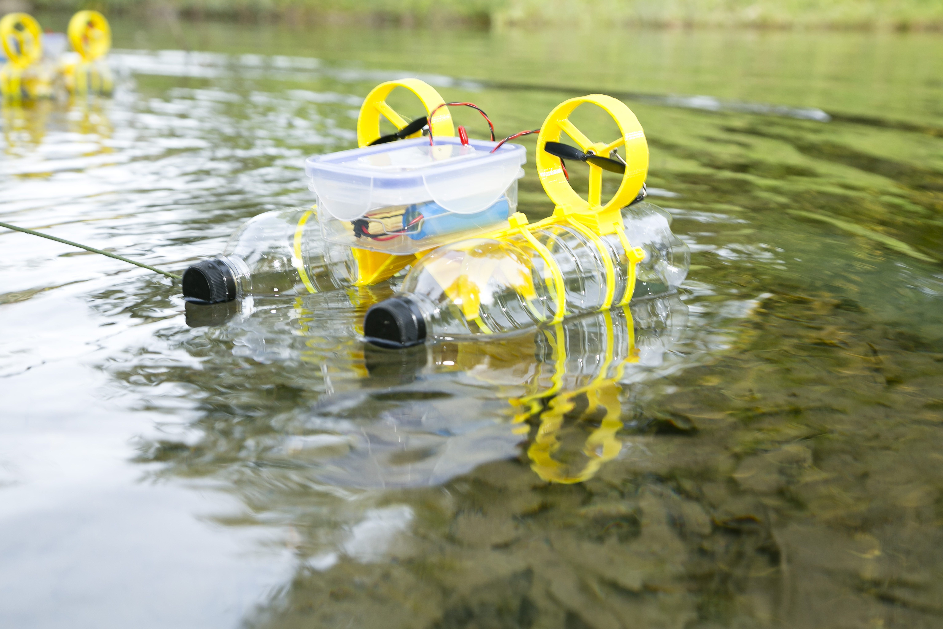
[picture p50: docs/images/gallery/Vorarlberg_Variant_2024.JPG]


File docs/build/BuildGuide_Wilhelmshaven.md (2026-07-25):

# Build Guide (archived - Wilhelmshaven setup)

> This is the older build guide for the Wilhelmshaven workshop setup (1L bottle). It's kept here for
> anyone building that specific setup, but it's no longer the recommended starting point - see the
> [current Build Guide](./) (Vorarlberg setup) instead.

Keep in mind that the Mini Kenterprise is not set in stone. It is not a simple off-the-shelf kit with instructions that tell you 100% exactly how you should build it.
I encourage anyone to build their very own version of the Kenterprise.
However, especially for electronics beginners and also for student workshops it is great to have a little guide that you can follow along.
That is why I developed and documented the Mini Kenterprise version 1.

### 0. Get the materials
Below you can see a picture of the materials required to build a mini kenterprise.
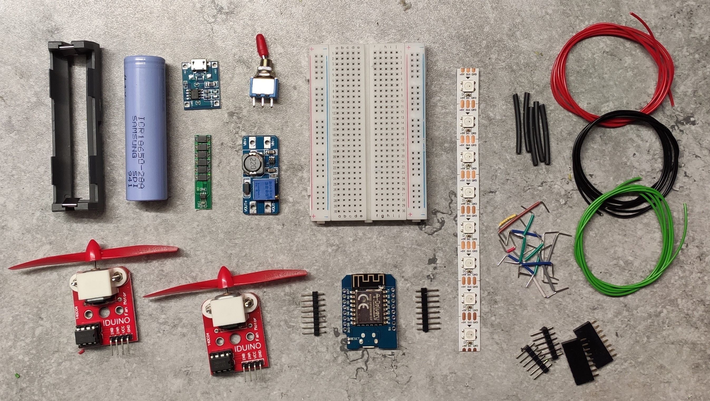
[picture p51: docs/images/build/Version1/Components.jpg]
Components

The exact parts might change, depending on availability and i am trying to keep an updated document with the [bill of materials here](../materials/BOM.md). The cost of building a Mini Kenterprise in Germany are currently (2024) around 35€.

### 1. Find and prepare 2 bottles
The biggest componente of a Mini Kenterprise are the two plastic bottles that help it to stay afloat. It is important that the bottles have thick plastic walls. These make the boat more rigid. Thin bottles tend to heavily deform when they are closed off and the temperature changes.
I like to use coke or sprite bottles, as they have thick and straight walls. Most manufacturers tend to give their bottles all kinds of funky shapes. Unfortunateley those funky shapes make it hard to connect them to the 3D printed components.
The size of bottle that you want to use is up to you. 0.5 liter bottles make for a small and fast boat. 1L bootles make the boat slower, as they are pretty heavy, but the also make it more stable and allow for a payload (maybe a sensor) to be carried.
I found 0.75L bottles to be a great middle ground.
Make sure to remove the label, so it doesn't peel of in the water. You can do that by filling the bottle with warm water. This liquifies the adhesive.Also try to remove any water from the inside with a paper towel and a long spoon.
Printing

### 2. Print the bridge and the fan enclosures
Apart from the bottles, there is a center piece called the bridege and two motor holders. These parts are made in a 3D printer. You can get the STL files under [`/3dFiles`](../../3dFiles).
Make sure to choose the right version for your motor and fan size 75mm(with 12mm motor) and your bottle size (0.5L or 0.75L).

Open them in the slicing software of your choice. [Cura](https://ultimaker.com/de/software/ultimaker-cura) is a good slicer for that.
It is best to print these parts out of PETG, as it is a very robust material, that doesn't deform on a hot summer day. Set the layer height to 0.4 mm. The parts where designed for 3D printing and don't need any support. The two fan mounts have to be printed with the flat side laying on the printbed.
Start the slicing process and export the file to an SD card, a USB drive, whatever your 3D printer uses and start printing.

### 3. Assemble the electronics
While the print is in progress you can prepare the interesting part of the boat (coming from an electrical engineer :D), the electronics.
The circuit diagram shows how all of the parts have to be connected.
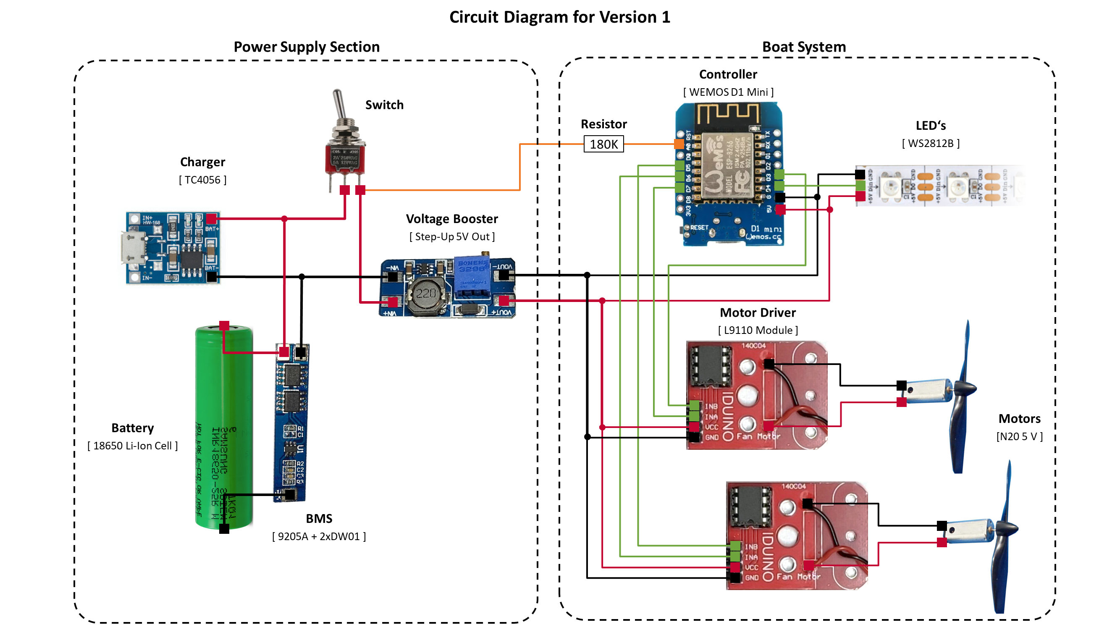
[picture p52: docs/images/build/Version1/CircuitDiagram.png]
Schematic


#### 3.1 Assemble the power supply section
The "power supply section" or in other words our selfmade powerbank should be assembled first. Quick sidenote, you can also use an actual powerbank. The circuit diagram for this variant can be found under [`docs/images/build/Version1/CircuitDiagramPowerbank.png`](../images/build/Version1/CircuitDiagramPowerbank.png). But if you decide to use an of the shelf powerbank, the microcontroller will not be able to read the current battery voltage. Therefore the companion website can not tell you how much battery you have left.
You can in theory put everything together on a breadboard.
Howerver, I would not reccomend this when it comes to power supply components, as the potential to plug something in the wrong way and fry your whole circuit or even start a battery fire is quite big.
Therefore all of the power supply components should be soldered togehter as seen in the following picture.
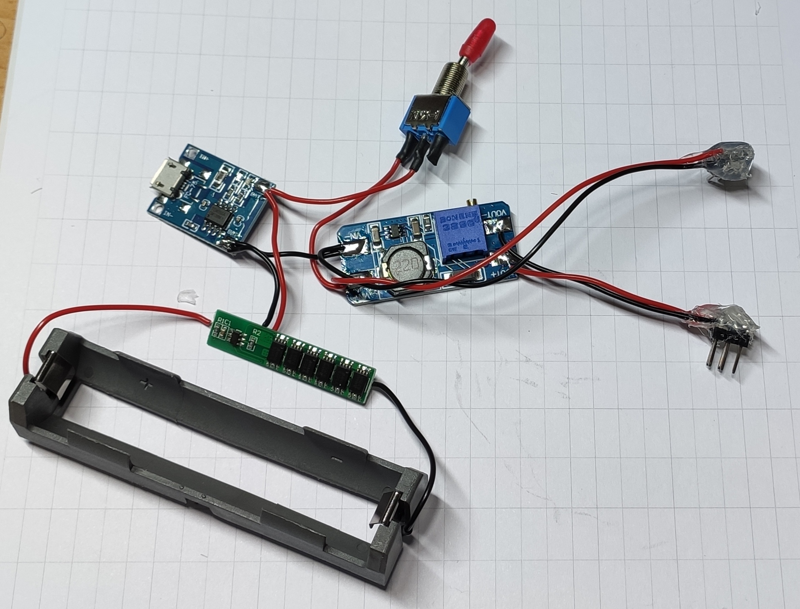
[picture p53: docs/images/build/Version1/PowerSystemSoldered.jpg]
Power Supply


#### 3.2 Solder Wires and Pins to further Components
The rest of the components will be plugged into a breadboard, this makes it easy to change and expand your Mini Kenterprise in the future. Maybe you want to switch to different motors, or you want to add a sensor.
A breadboard makes that possible without having to pull out the soldering ion every time. However, you will have to add so called "header pins" to your components, to be able to comfortably plug them into the breadboard.
Soldering Tips
The best starting point for your soldering work are the modules, such as the microcontroller. Stick the pins into your breadboard and place the PCB (aka the board) on top.Then you can solder one pin at a time. Keep in mind to not heat anything up for too long (a few seconds not half a minute). The solder should flow nice and evenly and cover the metal rings on the board as well as your pins. A good soldering joint has an even surface.

The power supply connectors are probably the most important pins. These can be seen in the image below. I use three pins for each power rail. This way I inclrease the contact surface and make sure that it works, even if one pin is a little bit loose.
I also like to use a combination of 2 pins and 3 pins and block one hole in the breadboard, as shown in the picture.
This way i instantly know ho to plug it in. When there is two power rails, with two connectors, i make sure to remove one pin on each side, so i can not accidentially switch them around.

Most components, such as switches come without wires, so you will have to solder wires to them with. Be sure to tin the wire and the surface you want to solder to first.
To connect the two you then just have to hold them together and heat them up with the soldering ion before the tin connects them. Don't heat them up for too long, as the heat can melt the plastic bodies of the components.
Isolate each connection with some shrink tubing, hotglue or electrical tape.

Some modules don't really fit on the breadboard, or take up too much space. One of such modules is the motor module. You can modify it, by removing the motor from the board, and soldering long wires ( 25cm ) to it.
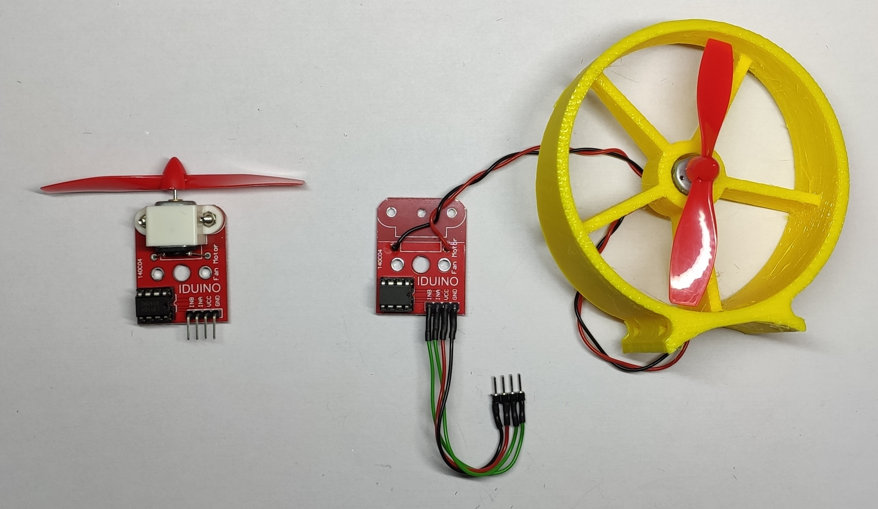
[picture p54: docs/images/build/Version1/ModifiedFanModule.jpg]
Modified module


#### 3.3 Assemble the Breadboard
When you are done soldering, you can simply plug everything into the breadboard.
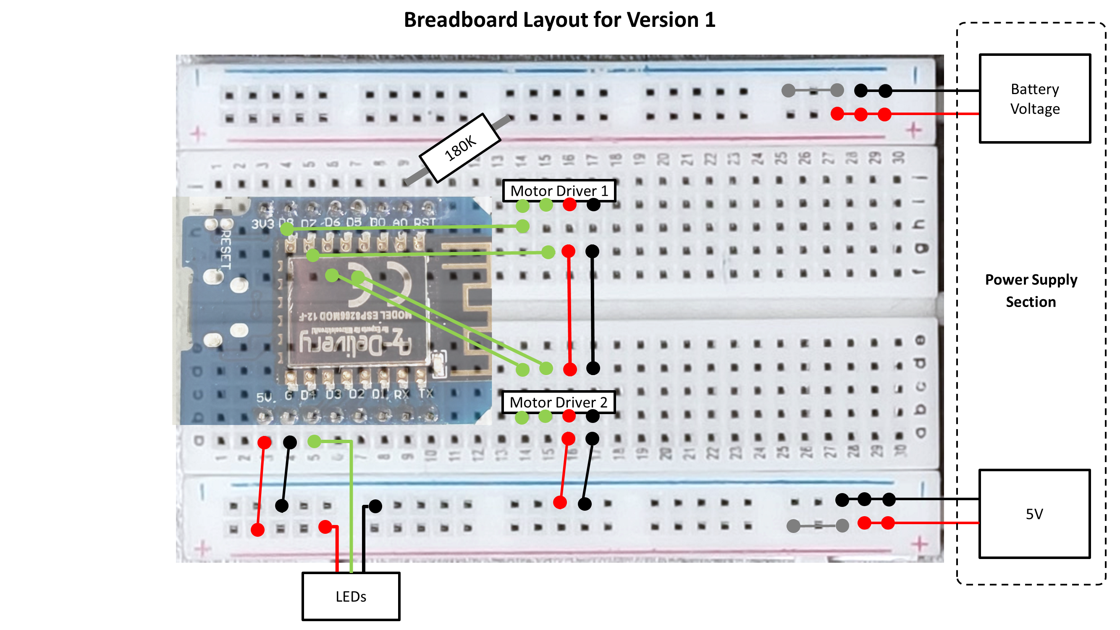
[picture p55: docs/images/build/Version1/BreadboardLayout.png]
Breadboard

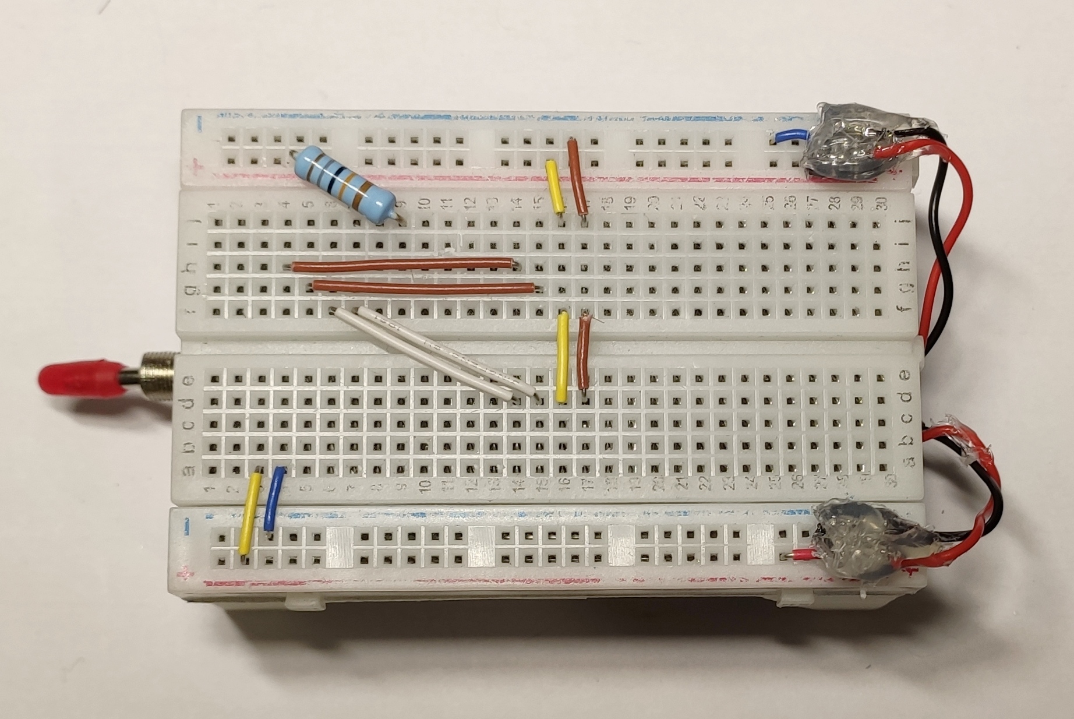
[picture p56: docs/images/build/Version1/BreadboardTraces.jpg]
Breadboard


### 4. CHECK YOUR CONNECTIONS and hook everything up
Measuing
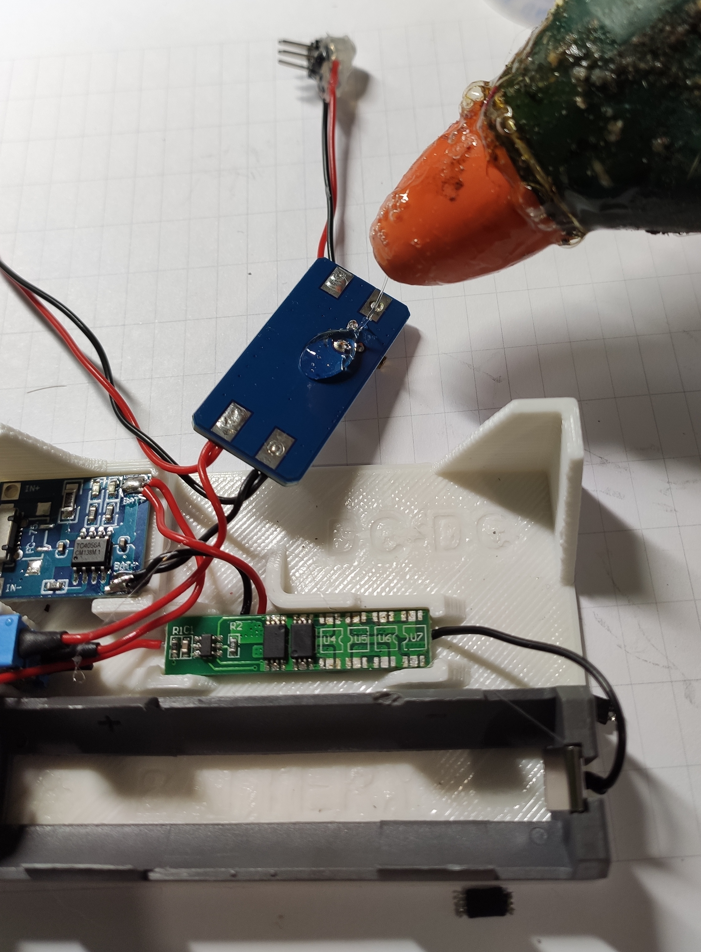
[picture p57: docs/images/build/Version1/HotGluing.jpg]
Power Supply Assembled

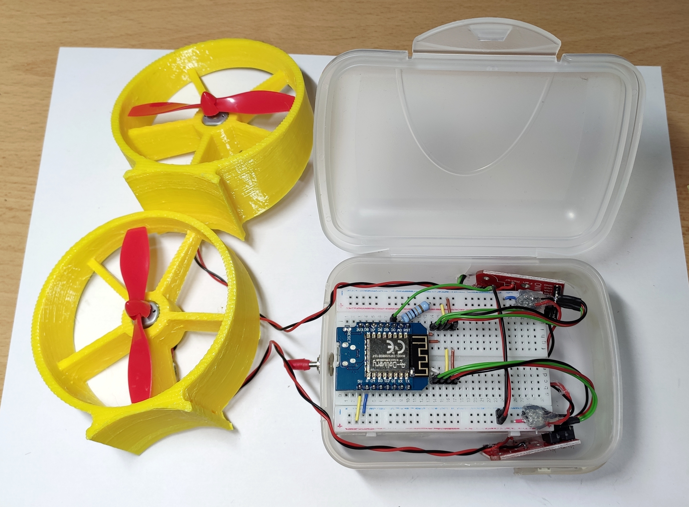
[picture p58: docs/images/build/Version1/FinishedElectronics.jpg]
Finished Electronics


### 5. Program the microcontroller
No Arduino IDE required. Go to the [Mini Kenterprise flashing website](https://basementengineering.github.io/MiniKenterprise/), plug your boat's microcontroller into your PC via USB, and click the install button (works in Chrome or Edge). That's it - the firmware, including the on-device Control UI, gets flashed straight from your browser.

If you're building "Version 1" from this guide, the default pins and WiFi settings already match your hardware, so there is nothing else to configure. If you built a different pin layout or want a different WiFi name/password, you can change those later from the boat's own settings page (see step 6) instead of editing any code.

If you'd rather build the firmware yourself (e.g. to modify it), the source lives under [`/MiniKenterpriseCode`](../../MiniKenterpriseCode), the on-device Control UI source under [`/minikenterprise_frontend`](../../minikenterprise_frontend), and `deployFrontend.ps1` (repo root) rebuilds the Control UI and regenerates the headers the firmware embeds it from. See [`docs/DEVELOPMENT.md`](../DEVELOPMENT.md) for the full local development workflow (frontend dev server, testing, firmware upload, running the site locally).

### 6. Put the boat into operation
After being turned on the boat acts as a WiFi Access Point that devices can connect to.
Take your phone and search for the WiFi Network. By default this is called `MiniKenterprise_1` (password `RowYourBoat`) - you can change both, along with the pin assignments, from the boat's settings page at any time.
After you are connected to the WiFi your phone is probably going to tell you that the network has no internet connection and reccomend to change networks.
Sometimes the phone even switches to another network or to mobile automatically. Make sure that you catch the popup message and tell your phone that it is ok to stay in this network.
Now you want to open a webbrowser and enter get to the controller website. This can be done by entering the IP address 1.2.3.4 into the browsers address field.
This will bring you to a little website that looks like this:
Website
Time to confirm that the motors are working. Switch to mode 3 (buttons at the bottom).
Move the right stick all the way to the front. The right motor should start pushing air out the back. If the left motor starts spinning, you can simply switch the motor connectors around. If the motor pushes backwars, you can turn its connector around (switch + and  -).
Repeat the test for the left side.

### 7. Connect and charge the battery
Plug a Micro USB cable into the charging board. The LED should turn red, indicating that the battery is being charged. After 2 to 3 hours the LED will turn blue.

### 8. Use it
Now your boat is working properly and has a fully charged battery. Time to head to the lake.
Make sure that the weather is not too windy and not too rainy. It is also much more fun to play around in the sunshine.
Turn on your boat, connect your phone and take it for a spin on the water.
Try out the 4 different driving modes and figure out which one you like the most.
Keep an eye on the battery, if it consistently dips below 3.2V it is empty. If the voltage sinks too low, the BMS is going to disconnect the battery and leave your boat unmanouverable. Also make sure to stay in a range of about 20m and keep a long stick or a fishing line at hand, in case the boat gets stuck somewhere:D.

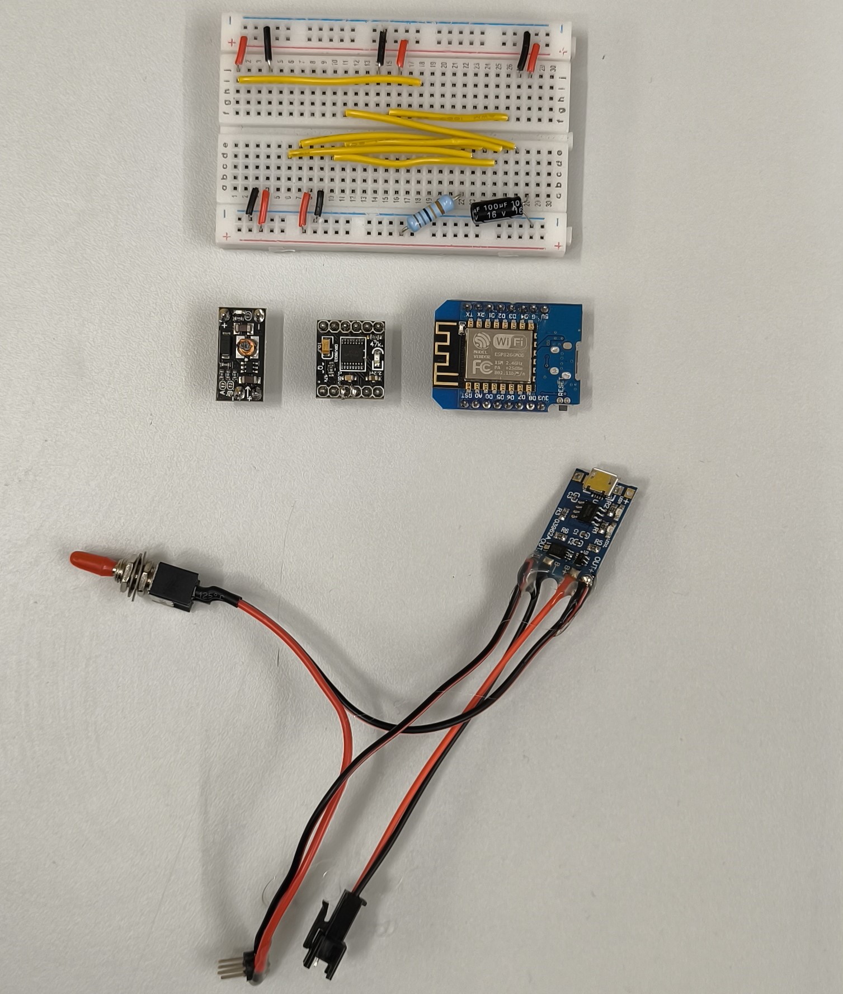
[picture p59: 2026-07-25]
docs/images/build/Komponenten.jpg

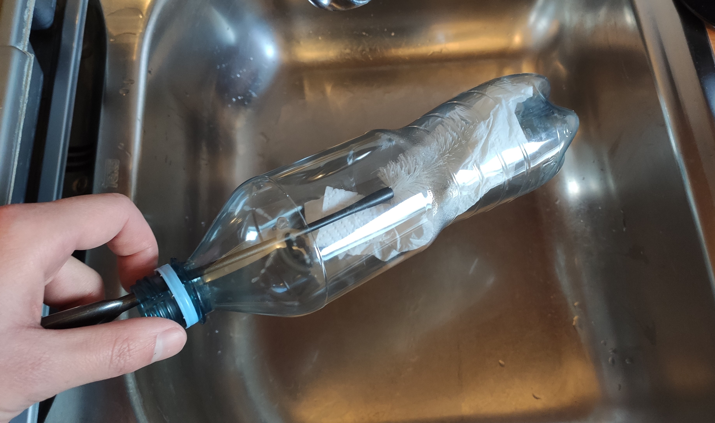
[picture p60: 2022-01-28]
docs/images/build/PrepareBottle.jpg

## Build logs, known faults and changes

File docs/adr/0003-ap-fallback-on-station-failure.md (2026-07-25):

# Automatic fallback to AP mode when Station-mode connection fails

WiFi mode (AP vs. Station) and credentials are now runtime-editable instead of compile-time constants, which means a builder can enter a wrong password or move out of range of the configured network. Without a recovery path, that would strand a non-technical builder with no way to reach the boat to fix it short of reflashing. We instead have the firmware time out a failed Station-mode connection attempt at boot and automatically fall back to hosting its own AP with the last-known AP credentials, so the device is always reachable to correct its settings.

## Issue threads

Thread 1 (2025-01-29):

Halter für Elektronik fehlt

Grischka24, 2025-01-29:
Der Halter für die Elektronik komponenten (Power Supply) fehlt ist es möglich die STL zu dem Halter zu bekommen.
Ich möchte die Version 1 bauen aber auch bei den anderen Versionen fehlt der Halter.

Paddy65305, 2025-02-20:
@BasementEngineering But as you use the deprecated FileSystem, move now th LittleFS by just changing the Class in the FrontendServer and now its possible to use the newest Arduino, as there exist a Upload-Plugin for it.

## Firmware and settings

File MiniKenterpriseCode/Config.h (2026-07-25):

#ifndef CONFIG_H
#define CONFIG_H

/*** Compile-time defaults ***
 * These are only used once, to seed Settings (see Settings.h) the first time
 * the device boots (or after a factory reset). Everything below is
 * runtime-editable afterwards from the on-device settings page - changing a
 * value here only changes what a *fresh* device starts out with.
 */

// Default Access Point credentials (the boat's own network)
#define DEFAULT_AP_SSID "MiniKenterprise_1"
#define DEFAULT_AP_PASSWORD "RowYourBoat"
#define MAX_WIFI_CONNECTIONS 1

// Default Station credentials - left blank; join a network from the settings page
#define DEFAULT_STA_SSID ""
#define DEFAULT_STA_PASSWORD ""

/*! The Pin Markings on the WEMOS D1 Mini Board don't match the GPIO numbers !
 * Do not use GPIO 0 aka. D3 as it is used for flashing programs.
 *
 * GPIO16 aka. D0 lives on the RTC domain instead of the main GPIO controller
 * (its own registers, used for deep-sleep wake), so it can't be used with
 * attachInterrupt(). It has supported analogWrite()/PWM since the earliest
 * ESP8266 Arduino core releases (confirmed back to 2.0.0-rc2) though, so it's
 * fine to use for motor speed control - the "GPIO16 can't do PWM" claim
 * floating around online is a myth.
 *
 * Pinout Table:
 * Wifi Antenna = Top
 * | Left Side        | Right Side    |
 * ------------------------------------
 * | RST      | RST   | TX    | GPIO1 |
 * | ADC0     | A0    | RX    | GPIO3 |
 * | GPIO16   | D0    | D1    | GPIO5 |
 * | GPIO14   | D5    | D2    | GPIO4 |
 * | GPIO12   | D6    | D3    | GPIO0 |
 * | GPIO13   | D7    | D4    | GPIO2 |
 * | GPIO15   | D8    | G     | GND   |
 * | 3.3V Out | 3V3   | 5V    | 5V In |
 * USB Port = Bottom
 */

// Default pins (previously "VERSION3")
#define DEFAULT_MOTOR_EN 15 //D8
#define DEFAULT_MOTOR_IN1 13 //D7
#define DEFAULT_MOTOR_IN2 12 //D6
#define DEFAULT_MOTOR_IN3 14 //D5
#define DEFAULT_MOTOR_IN4 16 //D0

// The LED strip is driven via the ESP8266's UART1 hardware (LightBar.h) rather than
// bit-banged, so its data pin is fixed to GPIO2/D4 (UART1 TX) and isn't configurable -
// don't assign GPIO2 to anything else above.
#define DEFAULT_LED_COUNT 8

// Fallback PWM limits used when voltageBasedPwmLimitEnabled is turned off in Settings (see
// PropulsionSystem::getCurrentPwmLimitBand()) - matches the previous static defaults from
// before voltage-based limiting existed.
#define DEFAULT_MANUAL_REGULAR_PWM_LIMIT_PERCENT 75
#define DEFAULT_MANUAL_BOOST_PWM_LIMIT_PERCENT 100

//Motor Settings (not runtime-configurable - tune per hardware and reflash)
#define MIN_PWM_L 30
#define MIN_PWM_R 30
#define MAX_PWM_L 255
#define MAX_PWM_R 255

// The DRV8833 thermally shuts off after ~45s at full throttle (as little as 10s if already
// warm) - and field testing showed the real driver is battery voltage: at a fresher/higher
// voltage the same PWM% delivers more current and heats it much faster (boosting 50%->75% at
// 4.1V overheated within 1s). So the PWM ceiling is looked up from the battery's last known
// no-load (rested) voltage - not the live/loaded reading, which sags under motor current and
// doesn't reflect true state of charge - via PropulsionSystem. Bands are ordered highest-
// voltage-first; the first one whose minNoLoadVoltageMv is <= the current reading wins.
struct PwmLimitBand {
  int minNoLoadVoltageMv;
  uint8_t regularPercent;
  uint8_t boostPercent;
};
#define PWM_LIMIT_BAND_COUNT 3
// static: Config.h is included from more than one .cpp translation unit (the .ino and
// PropulsionSystem.cpp) - without internal linkage this array would be multiply defined at
// link time. Everything else in this file is a preprocessor macro, so this didn't matter until
// now, this is the first actual variable definition living in this header.
static PwmLimitBand pwmLimitBands[PWM_LIMIT_BAND_COUNT] = {
  { 4000, 50, 60 },  // 4.0-4.2V (fresh battery) - lowest ceiling, hottest per-% behavior
  { 3700, 55, 75 },  // 3.7-4.0V
  {    0, 75, 100 }, // below 3.7V
};

// Boost window and mandatory cooldown before it can be used again (see PropulsionSystem).
#define BOOST_DURATION_MS 5000
#define BOOST_COOLDOWN_MS 30000

#define TRIM 0.0F

#define DEBUG

#endif

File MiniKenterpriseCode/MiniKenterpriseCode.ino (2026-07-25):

#include "Config.h"
#include "Settings.h"
#include "PropulsionSystem.h"
#include "RudderPropulsion.h"
#include "LightBar.h"
#include "Battery.h"
#include "Wifi.h"
#include "FrontendServer.h"
#include "Parser.h"

// Constructed in setup(), once Settings_load() has read the pin assignments -
// global objects can't take these as constructor args since Settings isn't
// loaded yet when global initializers run.
//
// RudderPropulsion (rudder-steered boat variant, from origin/main) is included
// above but not yet wired in here - it assumes a compile-time pin scheme this
// firmware doesn't use anymore (pins are runtime-configurable via Settings).
// Revisit if/when rudder steering becomes a selectable Settings-driven mode.
PropulsionSystem* propulsionSystem;
LightBar* lightBar;

enum State{
  STARTING_WIFI,
  WAITING_FOR_WIFI_CLIENT,
  WAITING_FOR_FRONTEND,
  WORKING
 };

 State state = STARTING_WIFI;

//helper function decalarations (full implementations are further down)
void switchState(State newState){
  Serial.println("Switching state ");
  Serial.print(state);Serial.print(" to ");Serial.println(newState);
  if(newState != WORKING){
    propulsionSystem->stop();
  }
  if(newState == STARTING_WIFI){
    // Always start a fresh Station-connect attempt here - covers the initial boot attempt,
    // losing an established Station connection, and the periodic retry from AP mode below.
    Wifi_resetStationAttempt();
  }
  state = newState;
  showStatus(state);
}

void setup(){
  Serial.setDebugOutput(true);
  Serial.begin(115200);
  Serial.println("Starting Setup");
  Settings_load();
  Serial.println("Motor pins: en=" + String(settings.motorEn) + " in1=" + String(settings.motorIn1) + " in2=" + String(settings.motorIn2) + " in3=" + String(settings.motorIn3) + " in4=" + String(settings.motorIn4));
  propulsionSystem = new PropulsionSystem(settings.motorEn, settings.motorIn1, settings.motorIn2, settings.motorIn3, settings.motorIn4);
  lightBar = new LightBar(settings.ledCount);
  // Battery_init() must run before propulsionSystem->initPins() - initPins() does the first
  // PWM-limit-band lookup (see PropulsionSystem::getCurrentPwmLimitBand()) using the no-load
  // voltage reading immediately, which Battery_init() is what seeds with a real sample.
  Battery_init();
  propulsionSystem->initPins();
  lightBar->initLeds();
  lightBar->setMode(SOLID);
  lightBar->setMainColor(200,50,0);
  Wifi_setup();
  lightBar->setMode(BLINKING);
  //lightBar.update()

  Serial.println("Starting Backend");
  Parser_setup(motorCallback,ledCallback);
  Parser_init();
  Serial.println("Ready");
}

void loop(){
  updateHardware();
  Wifi_update();
  FrontendServer_update();
  Parser_update();

  if(Battery_isCritical()){

  }

  if(Parser_online()){
   refreshStatus();
  }

  runStateMachine();
  checkWifiWedge();
  logDiagnostics();
}

// --- WiFi/AP wedge watchdog ---
// Observed in the field: the soft-AP can silently stop broadcasting (it vanishes from a phone's
// WiFi scan) while the rest of the firmware keeps running normally (state machine, LEDs, main
// loop all unaffected) - the crash is isolated to the WiFi/RF subsystem. Re-calling
// WiFi.softAP()/WiFi.begin() from software doesn't reliably clear whatever internal state caused
// that, so once we've had a working connection and it doesn't come back within a generous grace
// period, a full restart is the only recovery that's actually reachable for a boat out on the
// water (nobody's there to power-cycle it by hand).
#define WIFI_WEDGE_RESTART_TIMEOUT 90000
bool everHadWifiClient = false;
unsigned long lastWifiClientTime = 0;

void checkWifiWedge(){
  if(Wifi_connected()){
    everHadWifiClient = true;
    lastWifiClientTime = millis();
  }
  else if(everHadWifiClient && (millis() - lastWifiClientTime) > WIFI_WEDGE_RESTART_TIMEOUT){
    Serial.println("No WiFi client for " + String(WIFI_WEDGE_RESTART_TIMEOUT/1000) + "s after a previous connection - restarting (possible AP/radio hang)");
    propulsionSystem->stop();
    ESP.restart();
  }
}

// --- Heap diagnostics ---
// Logged periodically over Serial so a bench/tethered test run can show whether heap
// fragmentation builds up over a session - a candidate contributor to the same WiFi/AP
// instability, alongside the NeoPixel interrupt-blackout issue above.
#define DIAGNOSTICS_LOG_INTERVAL 5000
unsigned long lastDiagnosticsLog = 0;

void logDiagnostics(){
  if( (millis() - lastDiagnosticsLog) > DIAGNOSTICS_LOG_INTERVAL){
    lastDiagnosticsLog = millis();
    Serial.print("Heap: free=");
    Serial.print(ESP.getFreeHeap());
    Serial.print(" maxFreeBlock=");
    Serial.print(ESP.getMaxFreeBlockSize());
    Serial.print(" fragmentation=");
    Serial.print(ESP.getHeapFragmentation());
    Serial.println("%");
  }
}

//STATE MAchines
void runStateMachine(){
  // Running AP mode only as a fallback (the user actually wants Station mode) - periodically
  // check whether the home network is reachable again, as long as nobody is currently
  // connected/driving through the AP. Skipped while already (re-)attempting Station mode.
  if(state != STARTING_WIFI && Wifi_shouldRetryStation()){
    Serial.println("Retrying Station mode after fallback to AP");
    switchState(STARTING_WIFI);
  }

  switch(state){
    case STARTING_WIFI:
      Wifi_start();
      if(Wifi_online()){
        FrontendServer_init();
        switchState(WAITING_FOR_WIFI_CLIENT);
      }
      break;
    case WAITING_FOR_WIFI_CLIENT:
      if(Wifi_connected()){
        Serial.println("Wifi is connected");
        setTimeout(100000);
        Serial.println("SetTimeout done");
        switchState(WAITING_FOR_FRONTEND);
      }
      if( timoutDone() ){
          Serial.println("Restarting");
          ESP.restart();
      }
      //Serial.println("Waiting for wifi client doen");
      break;
    case WAITING_FOR_FRONTEND:
      if(Parser_online()){
        //FrontendServer_stop();
        resetTimeout();
        switchState(WORKING);
      }
      if(!Wifi_connected()){
        FrontendServer_start();
        //switchState(WAITING_FOR_WIFI_CLIENT);
        switchState(STARTING_WIFI);
      }
      break;
    case WORKING:
      if(!Parser_online()){
        setTimeout(30000);
        switchState(WAITING_FOR_FRONTEND);
      }
      break;
    default:
      break;
}
}

void showStatus(int stateCode){
  switch(stateCode){
    case STARTING_WIFI:
    case WAITING_FOR_WIFI_CLIENT:
      // Blue = trying to join/connected to the home network (Station mode).
      // Magenta = broadcasting the boat's own network (AP mode, whether by choice or
      // fallback) - lets you tell at a glance which network to look for on your phone.
      if(Wifi_isApMode()){
        lightBar->setMainColor(200,0,200);
      }
      else{
        lightBar->setMainColor(0,0,255);
      }
      lightBar->setMode(BLINKING);
      break;
    case WAITING_FOR_FRONTEND:
      lightBar->setMainColor(0,200,000);
      lightBar->setMode(BLINKING);
      break;
    case WORKING:
      lightBar->setMainColor(YELLOW);
      lightBar->setMode(KNIGHT_RIDER);
      break;
    default:
      break;
  }
}

//Timeout helpers
unsigned long timeout = 0;
bool timerActive = false;
unsigned long timeoutStart = 0;

void setTimeout(unsigned long maxValue){
  timerActive = true;
  timeout = maxValue;
  timeoutStart = millis();
}

void resetTimeout(){
  timerActive = false;
}

bool timoutDone(){
  if(timerActive){
    if( (millis() - timeoutStart) > timeout){
      timerActive = false;
      return true;
    }
  }
  return false;
}


//Regular Update helpers
void updateHardware(){
  Battery_update(propulsionSystem->isIdle());
  lightBar->update();
  propulsionSystem->update();
  yield();
}

void motorCallback(Command command){
  //Serial.println("Movement callback");
  //Serial.println("command.id");
  //Serial.println(command.id);
  int leftSpeed = 0;
  int rightSpeed = 0;
  
  switch(command.id){
    case ControlLR:
      leftSpeed = command.parameters[0];
      rightSpeed = command.parameters[1];
      propulsionSystem->moveLeft(leftSpeed);
      propulsionSystem->moveRight(rightSpeed);
      break;
    case ControlSD:
      propulsionSystem->setSpeed(command.parameters[0]);
      propulsionSystem->setDirection(command.parameters[1]);
      break;
    default:
    //Serial.println("in switch");
    break;
  }

  // Boost-requested flag, appended as a 3rd parameter to the periodic ControlLR/ControlSD
  // command - guarded by parameterCount so older frontend builds that don't send it are
  // unaffected. Applies regardless of which command id carried it (both funnel through here).
  if(command.parameterCount > 2 && command.parameters[2] == 1){
    propulsionSystem->requestBoost();
  }
}

void ledCallback(Command command){
  //Serial.println("LED Callback");
  if(command.parameterCount == 4){
    lightBar->setMode(command.parameters[0]);
    lightBar->setMainColor(command.parameters[1],command.parameters[2],command.parameters[3]);
  }
}

unsigned long lastStatusUpdate = 0;
void refreshStatus(){
  if( (millis() - lastStatusUpdate) > 100){
    lastStatusUpdate = millis();
    Command command;
    command.id = Status;
    command.parameterCount = 6;
    command.parameters[0] = Battery_getPercentage();
    command.parameters[1] = Wifi_getQualityPercentage();
    command.parameters[2] = Battery_getVoltageMv();
    command.parameters[3] = propulsionSystem->getBoostState();
    command.parameters[4] = propulsionSystem->getBoostSecondsRemaining();
    command.parameters[5] = Battery_getNoLoadVoltageMv();
    Parser_sendCommand(command);
  }
}

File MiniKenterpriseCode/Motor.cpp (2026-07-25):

#include "Motor.h"

Motor::Motor(int _en, int _in1, int _in2, int _minPwm, int _maxPwm){
  en = _en;
  in1 = _in1;
  in2 = _in2;
  minPwm = _minPwm;
  maxPwm = _maxPwm;
}

void Motor::initPins(){
  pinMode(en,OUTPUT);
  
  pinMode(in1,OUTPUT);
  pinMode(in2,OUTPUT);

  stop();
}

void Motor::enable(){
  digitalWrite(en,HIGH);
}

void Motor::disable(){
  digitalWrite(en,LOW);
}

void Motor::update(){
  if((millis() - lastUpdate) > updateInterval){
    lastUpdate = millis();
    float deltaPwm = (float)(maxPwm*updateInterval)/responseTime;
    float nextStep = 0;
    if(targetPwm > (currentPwm+deltaPwm) ){
      //Serial.println("Adding");
      nextStep = currentPwm + deltaPwm;
    }
    else if(targetPwm < (currentPwm-deltaPwm) ){
      //Serial.println("Subtracting");
      nextStep = currentPwm - deltaPwm;
    }
    else{
      nextStep = targetPwm;
    }
    
    if(currentPwm != targetPwm){
      moveMotor((int)nextStep);
      #ifdef DEBUG_MOTOR
      Serial.print("nextStep");
      Serial.println(nextStep);
      Serial.print("delta PWM");
      Serial.println(deltaPwm);
      Serial.print("Current PWM");
      Serial.println(currentPwm);
      Serial.print("Target PWM");
      Serial.println(targetPwm);
      #endif
    }
    
    currentPwm = nextStep;
  }
}

bool Motor::targetReached(){
  return currentPwm == targetPwm;
}

void Motor::stop(){
  currentPwm = 0;
  targetPwm = 0;
  digitalWrite(in1,LOW);
  digitalWrite(in2,LOW);
}

void Motor::setPower(int newPower){
  if(!polarity){
    newPower = -newPower;
  }
  
  if((newPower >= -100) && (newPower <= 100)){
    targetPwm = powerToPwm(newPower,minPwm,maxPwm);
  }
  else{
  targetPwm = 0;
  }

  #ifdef DEBUG_MOTOR
      Serial.println("Motor::setPower()");
      Serial.print("newPower: ");
      Serial.println(newPower);
      Serial.print("targetPwm ");
      Serial.println(targetPwm);
  #endif
}

int Motor::getPower(){
  return pwmToPower(currentPwm,minPwm,maxPwm);
}

int Motor::getTargetPower(){
  return pwmToPower(targetPwm,minPwm,maxPwm);
}

int Motor::powerToPwm(int power, int minPwm, int maxPwm){
  if(power == 0){
    return 0;
  }
  int magnitude = (((maxPwm-minPwm)*abs(power))/100)+minPwm;
  return (power > 0) ? magnitude : -magnitude;
}

int Motor::pwmToPower(int pwm, int minPwm, int maxPwm){
  if(pwm == 0){
    return 0;
  }
  int power = ((abs(pwm)-minPwm)*100)/(maxPwm-minPwm);
  return (pwm > 0) ? power : -power;
}

void Motor::moveMotor(int pwm){
  //digitalWrite(en,HIGH);

  if(pwm > 255){
    pwm = 255;
  }
  else if(pwm < -255){
    pwm = -255;  
  }
  
  if(pwm > 0){
    digitalWrite(in1,LOW);
    analogWrite(in2,pwm);
  }
  else if(pwm < 0){
    analogWrite(in1,-pwm);
    digitalWrite(in2,LOW);
  }
  else{
    digitalWrite(in1,LOW);
    digitalWrite(in2,LOW);
  }
}

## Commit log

2021-10-21 Initial Commit. Turning everything into a proper repository.
    [Fan_Enclosure.stl]
2021-10-21 Added german purchase links. Added battery holder to list of materials. Added 3D Files.
    [Centerpiece_Body.stl, Centerpiece_Cap.stl, FanHolder.stl]
2021-10-21 Fixed Links to STL files
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2021-10-21 Smothed the edges of the 3D Files and included cutouts for the electronics
    [Centerpiece_Body.stl, Centerpiece_Cap.stl]
2021-10-21 Added a couple of images of the assembled electronics
    [Centerpiece_Cap.stl]
2021-11-01 Added new 3D Model for simplified centerpiece (usable with any electronics enclosure. Changed the pin declarations to fit the newest hardware layout. Added a couple of comments. Incooperated an 8 LED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
    [CenterPiece_Flat.stl, Centerpiece_Body.stl]
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2021-11-01 Did multiple changes on the fan holder. It is now smaller and only uses one ziptie. Also updated the rendering
    [FanHolder.stl]
2021-11-17 Moved all of the led stuff from the main file into a seperated class called LightBar.
2021-11-23 The TP4056 charger module with build-in protection can not output enough current and therefore chokes the motors. Changed shematic to now include a separate BMS board and a charger board without buil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
2021-12-12 Created a smaller version for 0.5l bottles. The 3D files where added to the according subfolder
    [CenterPiece.stl, FanEnclosure.stl]
2021-12-12 Reworked the steering. There is now a Slider for direction as well as a slider for speed instead of two individual speed sliders for each motor. Also implemented a 'sticky' speed slider.
    [MiniKenterpriseCode.ino, PropulsionSystem.cpp, PropulsionSystem.h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]
2022-01-28 Added a lot of content to the readme. Version differentiation, soldering tips, and bottle finding information. Also added accompanying images.
2022-01-29 Added new 3D files
    [Bridge.stl, CenterPiece.stl, CenterPiece_Flat.stl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]
2022-02-01 Finally finished the first version of the all new frontend. It now uses a grid layout and flexbox components. The joysticks went from being simple sliders to full blown canvas based joysticks, that l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
    [PropulsionSystem.h, backend.h]
2022-03-24 Added dynamic joystick scaling for different screen sizes. Also added pin layout for V1
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2022-08-18 Fixed battery a little bit and implemented and tested reconnection
    [Battery.h, MiniKenterpriseCode.ino]
2022-08-19 Added pin names and fixed motor left right commands to use full range
    [Config.h, MiniKenterpriseCode.ino]
2022-08-21 Implemented automatic channel setting. Also changed default IP in AP Mode to 1.2.3.4. Furthermore fixed a little bug with the motors
    [Config.h, MiniKenterpriseCode.ino, Wifi.h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]
2022-09-10 changed steering to be slower and more gentle. Implemented motor min and max pwm. Implemented Wifi Station Mode
2023-08-17 Finally fixed websocket disconnection issue in station mode by setting the wifi_sleep mode to None:). Also added a class for rudder based boat steering for the lego boat. Furthermore added a way to s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
    [Config.h, MiniKenterpriseCode.ino, RudderPropulsion.cpp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]
2024-04-30 Did some minor Readme restructuring and spell checking. Removed a code error caused by a stricter cpp compiler requiring a return value at the end of a function. Added binaries
    [Battery.h]
2026-07-17 Exclude local Duck-main reference copy from version control
    Kept on disk for reference while porting its build pipeline, but it's a
    vendored sibling project's snapshot, not something this repo should track.
2026-07-17 Fix missing return in Battery::toPercentage()
    The fallthrough case had no return, which newer GCC treats as a hard
    error (-Werror=return-type) and broke compilation with current
    arduino-cli/esp8266 core versions. In practice this path is unreachable
    given the lookup table's range, so it just returns 0.
    [Battery.h]
2026-07-17 Add runtime Settings (WiFi + pins) with EEPROM persistence
    WiFi credentials and pin assignments were previously #define constants
    in Config.h, requiring a source edit and reflash for any change. They're
    now a flat struct persisted in EEPROM (magic-byte validated, falling
    back to Config.h defaults on first boot), loaded once in setup() and
    used to construct PropulsionSystem/LightBar and drive Wifi.h.
    AP-vs-Station mode is now a runtime choice instead of a compile-time
    #ifdef, and a failed Station-mode connection attempt automatically
    falls back to AP mode after a timeout, so a bad WiFi setting can't
    permanently strand the device.
    Deliberately kept flat (no per-motor driver types, no Prefere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
    [Config.h, MiniKenterpriseCode.ino, Settings.cpp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]
2026-07-17 Embed the Control UI in firmware instead of serving it from SPIFFS
    Replaces the old data/ folder (served from SPIFFS, requiring the
    Arduino-IDE-1.x-only "Sketch Data Upload" step) with a frontend built
    from minikenterprise_frontend/ (a Vite project forked from the Duck
    project's frontend - protocol-compatible, confirmed by diffing both
    Parser.h files) and baked directly into the firmware as PROGMEM byte
    arrays.
    tools/encodeInArduino.py (ported from Duck) generates
    website_content.h/website_functions.h from the Vite build output;
    deployFrontend.ps1 runs the whole build+encode+copy step. Generated
    headers are committed so the sketch compiles standalone.
    FrontendServer.h also gains a small se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
2026-07-17 Add browser-based flashing site and GitHub Pages workflow
    A minimal esp-web-tools install page (no build step, no 3D model like
    Duck's version) so builders can flash the firmware straight from
    Chrome/Edge over Web Serial - no Arduino IDE required.
    .github/workflows/pages.yml publishes flash-site/ via GitHub Actions,
    since Pages' branch-based UI only supports / or /docs as a source
    folder, and docs/ here is already used for workshop materials.
    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
2026-07-17 Document the new setup flow and record architecture decisions
    README's "Program the microcontroller" section now describes the
    browser-flashing workflow instead of Arduino IDE 1.x + Sketch Data
    Upload, and points to the settings page for WiFi/pin changes. Also
    fixes a stale IP (192.168.4.1 -> 1.2.3.4) that no longer matched the
    firmware's actual AP config.
    Adds CONTEXT.md (glossary: Settings, Config.h defaults, AP/Station
    mode, flash-site, Control UI) and three ADRs covering the decisions
    behind this work.
2026-07-18 Rework the Control UI settings page for mobile
    Fix the mobile scrolling/zoom bug (missing viewport tag), make the layout
    responsive, add a back button and a sticky/floating Save CTA, replace the
    AP/Station radio buttons with a switch (pictogram, clearer field labels,
    fallback note, and disabled Station fields while AP is active), add an
    ESP8266 pinout diagram, and add a German/English language switch.
    Also adds a local "Settings stub" dev server (see ADR 0004) so the page's
    load/save round-trip can be tested without a flashed board.
    [i18n.js, settings.js]
2026-07-18 Redesign the pinout diagram and add live GPIO assignment tags
    Integrate the hand-edited (Inkscape) pinout artwork - bigger antenna
    housing/module/USB connector, recolored module, two-line board label -
    cleaned of Inkscape editor cruft for the PROGMEM embed. Also recolor the
    GPIO reference labels to black, and annotate each pin with a live tag
    (EN/IN1-4/LED) showing which Motor/LED setting currently points at it,
    updating as the fields are edited.
    [settings.js]
2026-07-18 Add pin defaults reset and GPIO validation to the settings page
    Add a "Reset Pins to Defaults" button that fills the Motor/LED pin
    fields with Config.h's compile-time defaults (frontend-only, not
    saved until the user hits Save).
    Also validate the pin fields against the diagram's own known-GPIO
    list, so out-of-range or nonexistent GPIOs (e.g. 6-11, which aren't
    broken out on the Wemos D1 Mini) are flagged live and block Save via
    the form's native validity check.
    [i18n.js, settings.js]
2026-07-19 Replace settings-stub.js with a unified dev-stub covering boat control
    The Settings page had a local mock but the boat-control WebSocket
    channel didn't, so a missing backend during npm run dev looked
    identical to a real firmware bug. dev-stub.js now mocks both: the
    existing /api/settings HTTP protocol plus a ws server on :81 that
    decodes and logs live control commands (reusing parser.js as the
    single source of truth), replies to heartbeats, and drifts simulated
    battery/network status - so the whole Control UI can be built and
    debugged locally without hardware.
2026-07-19 Regenerate embedded website headers from the current frontend
    Re-runs tools/encodeInArduino.py output into MiniKenterpriseCode/ so
    the firmware embeds the settings-page layout changes (centered
    title, unified save bar) instead of a stale build.
2026-07-19 Fix motor PWM bugs and route propulsion through a soft-start ramp
    moveMotor()'s reverse branch called digitalWrite() with a computed PWM
    value (HIGH/LOW-only, so it always drove full power regardless of
    requested speed), the PWM formula was missing its minPwm offset, and
    translateToMotors()'s turning logic had left/right backwards versus
    its own comments. Also finishes wiring up Motor, which ramps PWM
    toward a target instead of jumping straight to it, protecting the
    battery/BMS from current spikes: PropulsionSystem now owns a Motor
    per side instead of doing analogWrite itself, and the .ino calls
    propulsionSystem->update() every loop tick to advance the ramp. Also
    fixes Motor.cpp's compile-br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
    [MiniKenterpriseCode.ino, Motor.cpp, PropulsionSystem.cpp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]
2026-07-19 Switch default motor pins to the Version 3 layout, document GPIO16
    Also notes that GPIO16/D0 has supported analogWrite()/PWM since the
    earliest ESP8266 Arduino core releases (verified back to 2.0.0-rc2) -
    its RTC-domain registers only rule out attachInterrupt(), not PWM
    output, contrary to a common claim.
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2026-07-20 Add boat configurator to flash-site alongside firmware flashing
    Builders can now pick a bottle size, driver, motor and prop (or a
    one-click Vorarlberg/Wilhelmshaven workshop preset) and get the
    matching BOM and 3D-printable STL downloads, instead of relying on
    scattered, drifted per-workshop BOM docs. flash-site's home page is
    now a chooser between flashing and configuring; deployConfiguratorAssets.ps1
    syncs the underlying 3D files and component/variant photos into the
    published site.
    [BOM_2024_WorkshopAustria.xlsx, Bridge.stl, CenterPiece.stl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]
2026-07-24 Restructure: consolidate public site under docs/, eliminate flash-site's copied assets
    flash-site/ needed everything GitHub Pages would serve to physically live
    inside it, so deployConfiguratorAssets.ps1 copied BOM component photos,
    variant hero photos, and a subset of 3dFiles/ STLs into flash-site/img/ and
    flash-site/downloads/ - and every copy got committed to git alongside its
    source, doubling real binary content for no benefit.
    - Move the site itself into docs/ (was flash-site/*), so it sits as a
    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
    [Bridge.stl, CenterPiece.stl, CenterPiece_ZiptieHoles.stl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]
2026-07-24 Add rotating gallery banner and redesign the home page
    - Home page hero image replaced with a rotating banner that crossfades
    through photos in docs/images/gallery/, with a caption (and optional
    location/year) underneath. Image list comes from gallery-manifest.json,
    regenerated by deployConfiguratorAssets.ps1 (mirrors the stl-manifest.json
    pattern) - captions/location/year are preserved across reruns once set
    by hand, never overwritten.
    - Added the Knight Rider effect gif/mp4 and a Maker Faire 2024 photo to
    the gallery rotation.
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2026-07-24 Add a Build Guide page with an archived-guide switcher
    - docs/build/index.html fetches and renders docs/build/BuildGuide.md
    client-side via the marked library (loaded from a CDN, same no-build-step
    approach as flash.html's esp-web-tools). It sits in the same folder as
    BuildGuide.md so the guide's relative image/file links resolve correctly
    without any rewriting.
    - BuildGuide.md is being rewritten to follow the Vorarlberg workshop setup
    (the current recommended starting point) with its own photos under
    docs/images/build/Vorarlberg/.
    - The previous guide (Wilhelmshaven setup) is preserved as
    BuildGuide_Wilhelmshaven.md rather than deleted, reachable via a small
    guide-switcher n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
2026-07-24 Fix case-mismatch in BuildGuide.md's Vorarlberg image links
    Links used lowercase "vorarlberg" while the actual folder is
    docs/images/build/Vorarlberg/ - worked locally on case-insensitive
    Windows, would have 404'd on GitHub Pages.
2026-07-25 Cherry-pick c9b1292: README spell-checking, drop redundant/no-op parts
    Cherry-picked from origin/main (c9b1292128fa72c4254e2b206e0c3ec381ed4281,
    "Did some minor Readme restructuring and spell checking. Removed a code
    error caused by a stricter cpp compiler requiring a return value at the
    end of a function. Added binaries"), reconciled as follows:
    - Battery.h: the "missing return" fix is a no-op here - this branch
    already fixed the same bug independently (63d5155), via a different
    code path that already returns on every branch.
    - README.md: kept our current (restructured) content throughout - the
    conflicting hunks were old, pre-restructuring text (duplicate BOM
    table, the Arduino-IDE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
2026-07-25 Cherry-pick 5187a29: WiFi sleep-mode fix, add dormant RudderPropulsion class
    Cherry-picked from origin/main (5187a29c62e746ecc1bb8bf95df216d87f26269a,
    "Finally fixed websocket disconnection issue in station mode by setting
    the wifi_sleep mode to None. Also added a class for rudder based boat
    steering for the lego boat. Furthermore added a way to switch between
    predefined pin configurations through defines."), reconciled as follows:
    - Wifi.h: kept the actual fix - wifi_set_sleep_type(NONE_SLEEP_T) in
    Wifi_start(), which addresses the station-mode websocket disconnects
    the commit message describes. Everything else in that commit's Wifi.h
    (the #ifdef AP_MODE compile-time branching, Wifi_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
    [MiniKenterpriseCode.ino, RudderPropulsion.cpp, Wifi.h]
2026-07-25 Add live battery voltage display
    Battery.h already computed the exact voltage internally (toVoltage() on
    the averaged ADC reading) but only ever returned the derived percentage,
    discarding it - added Battery_getVoltageMv() to expose it and send it as
    a 3rd Status command parameter (Parser.h's MAX_PARAM_COUNT is 6, only 2
    were in use).
    Frontend renders it as a small "3.7V"-style overlay on top of the battery
    icon rather than a separate readout, per feedback. dev-stub.js now
    simulates a drifting voltage too so this is testable without hardware.
    Guarded main.js's parsing so older firmware still sending only 2 status
    parameters doesn't break.
    [Battery.h, MiniKenterpriseCode.ino]
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2026-07-25 Fix joystick touch/scroll conflict on mobile
    touchmove had no preventDefault() and no touch-action CSS anywhere, so a
    drag on the joystick was also interpreted as a page scroll/pan gesture -
    whichever won that race broke the joystick. Fixed with touch-action: none
    on the joystick canvases/container (the modern fix, handles most current
    browsers) plus preventDefault() with { passive: false } in the touch
    listeners as a fallback for older ones (touchmove listeners default to
    passive, which silently no-ops preventDefault unless explicitly opted
    out). Also added overscroll-behavior: none as a backstop against iOS's
    rubber-band bounce scroll.
2026-07-25 Add Home Screen fullscreen support, expose dev server on the LAN
    Add-to-Home-Screen meta tags (apple-mobile-web-app-capable, etc.) so the
    Control UI runs fullscreen with no browser chrome once added to the home
    screen and launched from there - visiting the URL in a normal tab is
    unaffected, this only kicks in after that one manual step. Also tightens
    the viewport meta tag (initial/maximum-scale, viewport-fit=cover for
    notch safe-areas).
    vite.config.js had no `host` set, so the dev server only bound to
    localhost - added host: true so it's reachable from a phone on the same
    WiFi for testing without a flashed board.
2026-07-25 Redesign the Settings overlay
    Full visual rework of the in-canvas Settings popup (menu.js/index.html/
    style.css) - dark, centered dialog capped at min(90vw, 360px) instead of
    stretching edge to edge, sized down throughout for a landscape phone
    screen:
    - Input tab (now default, was Lights): Control Mode as a 2x2 grid of
    descriptive buttons (Arcade/Tank Drive x Auto-Center/Sticky) replacing
    generic "Mode 0-3" labels - verified these map exactly to the existing
    setMode(1-4) deadband/stickyness/rotation logic in ui.js, not just
    renamed. Motor Trim relabeled "Motor Trim (L/R)" with L/R end labels
    and a "35% Left"-style live readout instead of a bare number. Also
    fixed mode selection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
2026-07-25 Improve WiFi/AP fallback reliability
    Wait at least 30s for a Station connection before falling back to AP (was
    15s), and periodically retry Station mode every 30s while running AP as a
    fallback, as long as nobody is currently connected through it. Fixes a bug
    where losing an established Station connection caused an instant flip to
    AP with no real reconnect attempt, since the retry state was never reset.
    Also adds a self-recovery watchdog: the soft-AP can silently stop
    broadcasting while the rest of the firmware keeps running - if we've had a
    client and none reconnects within 90s, restart. Distinct LED colors now
    show Station vs AP mode, and heap stats are logged periodically over
    Serial to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
    [MiniKenterpriseCode.ino, Wifi.h]
2026-07-25 Drive LED strip via ESP8266 UART1 hardware instead of bit-banging
    Adafruit_NeoPixel disabled interrupts on ESP8266 for the whole duration of
    every show() call, a known cause of soft-AP/WiFi instability. Switches to
    NeoPixelBus's UART1 method, which paces the WS2812 bit timing with the
    UART's own hardware-clocked FIFO instead, so interrupts (including WiFi's)
    stay enabled throughout.
    This ties the LED data line to UART1's fixed TX pin (GPIO2), which was
    already this project's default LED pin and isn't used for anything else,
    so no rewiring is needed for existing boats. Since the pin is now a
    hardware constraint rather than a preference, removes the ledPin setting
    from Settings/EEPROM (bumpin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
    [Config.h, MiniKenterpriseCode.ino, Settings.cpp]
2026-07-25 Publish rebuilt firmware binary for web flashing
    Recompiled with the WiFi/AP fallback fixes and the UART1-driven LED
    strip.
2026-07-25 Add DRV8833 overheat protection: PWM limit + timed boost
    The DRV8833 thermally shuts off after ~45s at full throttle (as little as
    10s if already warm). Normal driving is now capped at a configurable
    percentage of max PWM (regularPwmLimitPercent, default 75%), with a boost
    button in the control UI that lifts the cap to boostPwmLimitPercent
    (default 100%) for a fixed 10s window followed by a mandatory 30s cooldown
    before it can be used again - both timings owned by the firmware
    (PropulsionSystem's boost state machine), not the client, since it must
    hold regardless of what the frontend sends.
    The boost request rides as a 3rd parameter on the existing periodic
    ControlLR/ControlSD commands, and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
    [Config.h, MiniKenterpriseCode.ino, PropulsionSystem.cpp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]
2026-07-25 Publish rebuilt firmware binary for web flashing
    Recompiled with DRV8833 overheat protection (PWM limit + timed boost).
2026-07-25 Add voltage-aware PWM limiting with a manual override
    Field testing showed the DRV8833 overheat problem is really driven by
    battery voltage: the same PWM% delivers more current (and heats faster)
    at a fresher/higher voltage. Normal driving and boost PWM limits are now
    looked up from three fixed bands keyed on the battery's no-load (rested)
    voltage, not the live/loaded reading - which sags under motor current and
    doesn't reflect true state of charge. Also drops boost duration to 5s.
    Battery.h gains a second, longer-averaged rolling buffer that only
    accumulates samples once both motors are confirmed idle
    (PropulsionSystem::isIdle()) for 400ms, letting the battery's own voltage
    sag actually re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
    [Battery.h, Config.h, MiniKenterpriseCode.ino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]
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2026-08-15 Added all 3d files for the different supportet motor sizes
    [BendingHelp.stl, BendingHelp_20.stl, FanEnclosure.scad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]
2026-08-15 Changed generated stl files to be binary stls so that they get downloaded as stl files and not shown as text.
    [FanEnclosure_05L_M12_P45.stl, FanEnclosure_05L_M12_P55.stl, FanEnclosure_05L_M12_P75.stl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]
2026-08-21 Added special version documetation, starting of with a simple page documenting the two wheeled kevin robot.
    [Baseplate.stl, MiddlePlate.stl, RearWheel_Holder.stl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]
2026-08-21 Sorted a couple of pictures and fixed a wiring mistake in the breadboard diagram for the Vorarlberg version
2026-09-01 Reworked the fan enclosure's mounting arm and spoke junctions in OpenSCAD: the arm now tapers from the guard ring down to a shorter, narrower foot near the bottle, and the spokes get proper rounded f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
    [FanEnclosure.scad]
2026-09-02 Improved the open scad script for the fan enclodure parts to reduce material use and weight, generate chamfers and have a smaller motor clearance. Rerendered all stls.
    [FanEnclosure.scad, FanEnclosure_05L_M12_P45.stl, FanEnclosure_05L_M12_P55.stl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]
2026-09-02 Added the LEGO Mini Kenterprise special edition: a paddle-wheel boat built from a LEGO hull with 3D-printed waterwheels and motor mounts, driven by waterproof N20 gear motors and powered by a USB pow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
    [MotorMount.stl, Waterwheel.stl]
2026-09-02 Added component photos (battery holder, propeller, coreless DC motor) to the BOM configurator, swapped the 18650 cell photo for a standalone shot, and added a click-to-enlarge lightbox for BOM thumbn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
2026-09-13 Updated the 0.75L and 1L bridge STLs and added a new Bridge.stl for the 0.5L bottle, wiring it up as that bottle's connector in the configurator (replacing the old centerpiece file). Regenerated stl-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
    [Bridge.stl]
